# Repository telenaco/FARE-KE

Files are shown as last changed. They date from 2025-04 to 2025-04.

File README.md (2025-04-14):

# FARE-KE: Framework for Affordable, Reliable Kinesthetic Evaluation



## Overview

<p align="center">
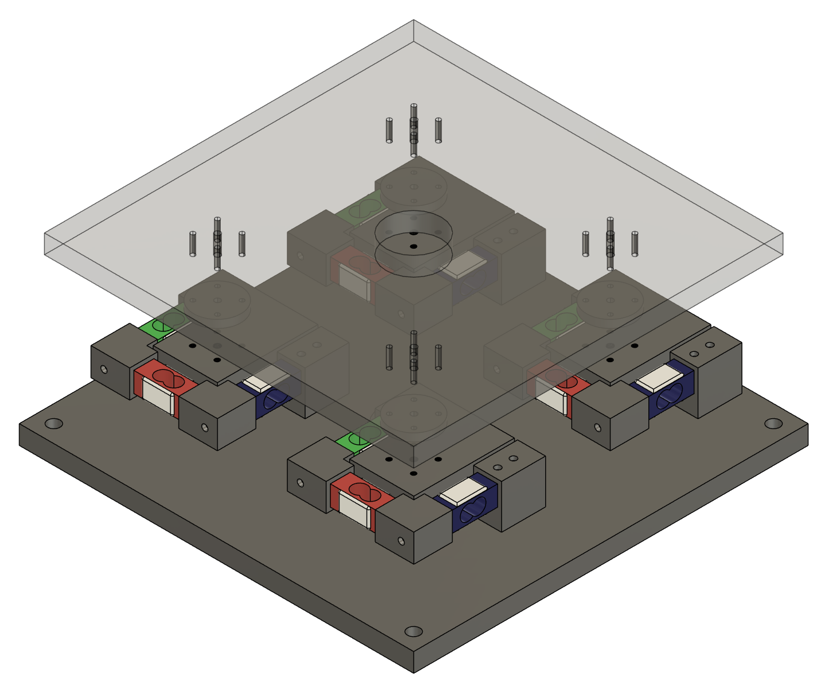
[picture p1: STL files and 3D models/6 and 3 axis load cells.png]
Figure 1: Load cell assembly
  
</p>

<p align="center"><span style="font-size: smaller;"><em>Figure 1: Exploded isometric view of the 6- and 3-axis load cell array assembly, showing the modular sensor housing units.</em></span></p>

FARE-KE is a comprehensive, standardized framework developed to address the growing need for accessible characterization methods for kinesthetic haptic devices. Born out of the challenges faced during the COVID-19 pandemic when laboratory access was limited, this framework provides researchers with the tools and methodologies to conduct precise haptic device evaluation using affordable components and open-source technologies.

The framework emerged from research on haptic device design and was refined through applications in three distinct case studies (VR Recoil, ProxyTouch, and HapticWhirl). FARE-KE aims to democratize haptic research by making characterization methods and tools accessible to researchers of all experience levels.

## Repository Structure

```
FARE-KE
├── Board_Evaluation
│   ├── ADC_Performance            # ADC testing and benchmarking studies
│   │   ├── adc_excitation_voltage_analysis  # Comparison of voltage stability
│   │   ├── adc_noise_variation_analysis     # Noise analysis at different OSR settings
│   │   └── adc_sampling_rate_analysis       # Evaluation of sampling performance
│   ├── Calibration_Methods        # Calibration methodologies for different load cells
│   │   ├── six_axis_calibration            # Matrix-based calibration approaches
│   │   └── three_axis_calibration          # Calibration for 3-axis sensors
│   └── Load_Cell_Comparison       # Comparative studies of load cell performance
│       ├── beam_load_cell_calibration      # Linear vs polynomial calibration
│       ├── beam_load_cell_comparison       # Temperature and drift analysis
│       └── hx711_vs_mcp3564_comparison     # Comparison of ADC performance
├── Haptic_Device_Testing
│   ├── Ramp_Response              # Implementation of ramp response analysis
│   │   ├── rampResponseAnalysis.py        # Analysis script for ramp data
│   │   └── rampResponseTelemetry.cpp      # Arduino code for ramp testing
│   └── Step_Response              # Implementation of step response analysis
│       ├── StepResponseAnalysis.py        # Analysis script for step data
│       └── stepResponseTelemetry.cpp      # Arduino code for step testing
├── MCP356x_Arduino_Library        # Core software components of FARE-KE
│   ├── lib/mcp356x                # Library for MCP356x ADCs
│   │   ├── examples               # Example implementations
│   │   │   ├── Basic              # Fundamental operations (reading, sampling)
│   │   │   ├── Calibration        # Calibration examples for different scenarios
│   │   │   ├── Comparison         # Comparison with other ADC technologies
│   │   │   ├── Filtering          # Signal filtering implementations
│   │   │   ├── LoadCells          # Multi-axis load cell configurations
│   │   │   └── Telemetry          # Data visualization and transmission
│   │   └── src                    # Core library source files
│   │       ├── MCP356x.cpp/h              # Base ADC interface
│   │       ├── MCP356x3axis.cpp/h         # 3-axis load cell support
│   │       ├── MCP356x6axis.cpp/h         # 6-axis force/torque plate
│   │       └── MCP356xScale.cpp/h         # Multi-load cell management
│   └── src                        # Main application code
├── MCP356x_DAQ_PCB_Board          # Hardware design for data acquisition
│   └── ffpcbBoard                 # Custom PCB for 12-channel data acquisition
│       ├── manufacturingPCB               # Gerber files for fabrication
│       └── PCB design files               # Schematics and BOM information
└── STL files and 3D models        # Physical components for framework implementation
    ├── 3-axis load cell STLs             # 3D printable parts for custom 3-axis sensors
    ├── 6-axis force plate STLs           # Components for force/torque plate assembly
    └── testbed designs                   # Mounting systems for various device types
```

## The FARE-KE Framework Architecture

FARE-KE consists of four integrated components to provide comprehensive haptic device characterization:

### 1. Hardware Framework

<p align="center">
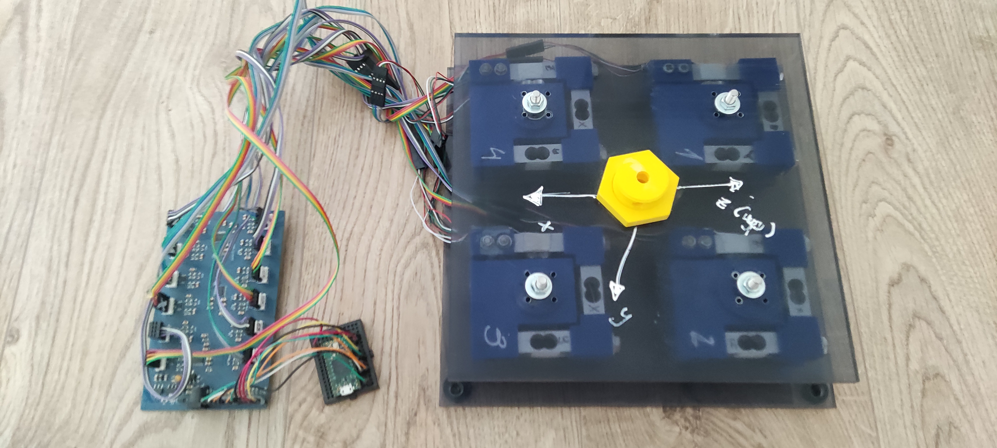
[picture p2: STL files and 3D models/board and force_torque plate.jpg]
Force/Torque Plate Assembly
  
</p>

<p align="center"><span style="font-size: smaller;"><em>Figure 2: Complete 6-axis force/torque plate with ADC board and wiring, showing the integrated system.</em></span></p>

**Key Components:**
- **Load Cells**: Single-axis beam load cells, custom 3-axis, and 6-axis configurations
- **Data Acquisition System**: Custom PCB design integrating 3 x MCP3564 ADCs for 12-channel capture
- **Testbeds**: Modular aluminum designs for mounting kinesthetic devices and sensors

**Testbed Designs:**
The framework recommends using extruded aluminum (40×40mm) for testbed construction due to:
- Standardization and wide availability
- Excellent structural rigidity (minimal vibrations)
- Abundant accessories for mounting and adaptation
- Easy reconfiguration for different device sizes

The testbeds must be designed to emulate the device's operational context and accommodate the same quantity and configuration of actuators as the final prototype to ensure representative data capture.

The framework supports five types of kinesthetic feedback modalities:

1. **Direct Single-Axis Force**: For devices applying linear force directly to the user
2. **Single-Axis Impact**: For devices generating sudden bursts of energy
3. **In-line Forces**: For cable-driven exoskeletons and similar devices
4. **Rotational Joint Torque**: For devices generating torque around a pivot point
5. **Multi-axis Force/Torque**: For complex haptic controllers with multiple degrees of freedom

### 2. Data Acquisition Framework

**Components:**
- **MCP3564 ADCs**: 24-bit sigma-delta converters supporting up to 153.6 kSPS sampling
- **Op-amp Based Amplification**: Customizable gain to optimize ADC range utilization
- **Teensy 4.0 Integration**: High-speed processing of multiple ADC channels

<p align="center">
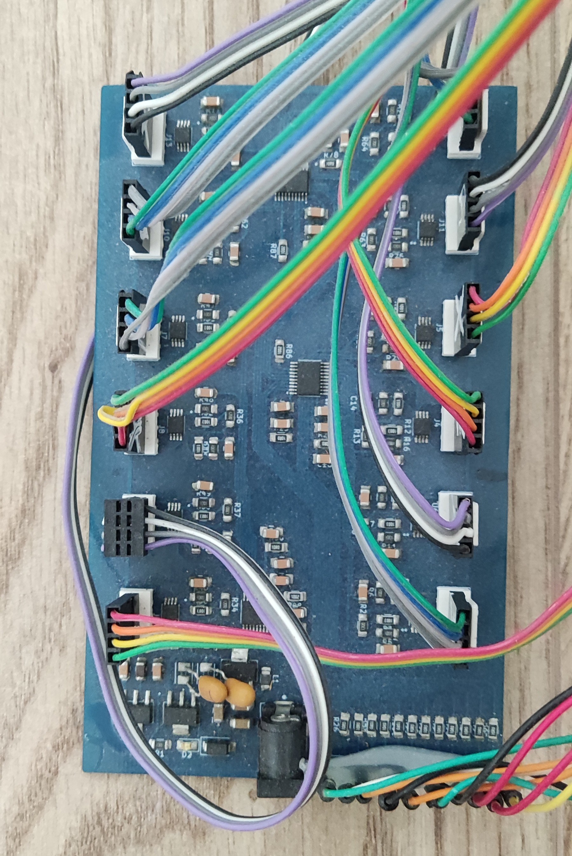
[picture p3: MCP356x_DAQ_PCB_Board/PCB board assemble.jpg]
DAQ PCB Board Assembly
  
</p>

<p align="center"><span style="font-size: smaller;"><em>Figure 4: Detailed assembly of the custom 12-channel Data Acquisition PCB, showing component layout and interconnections.</em></span></p>

<p align="center">
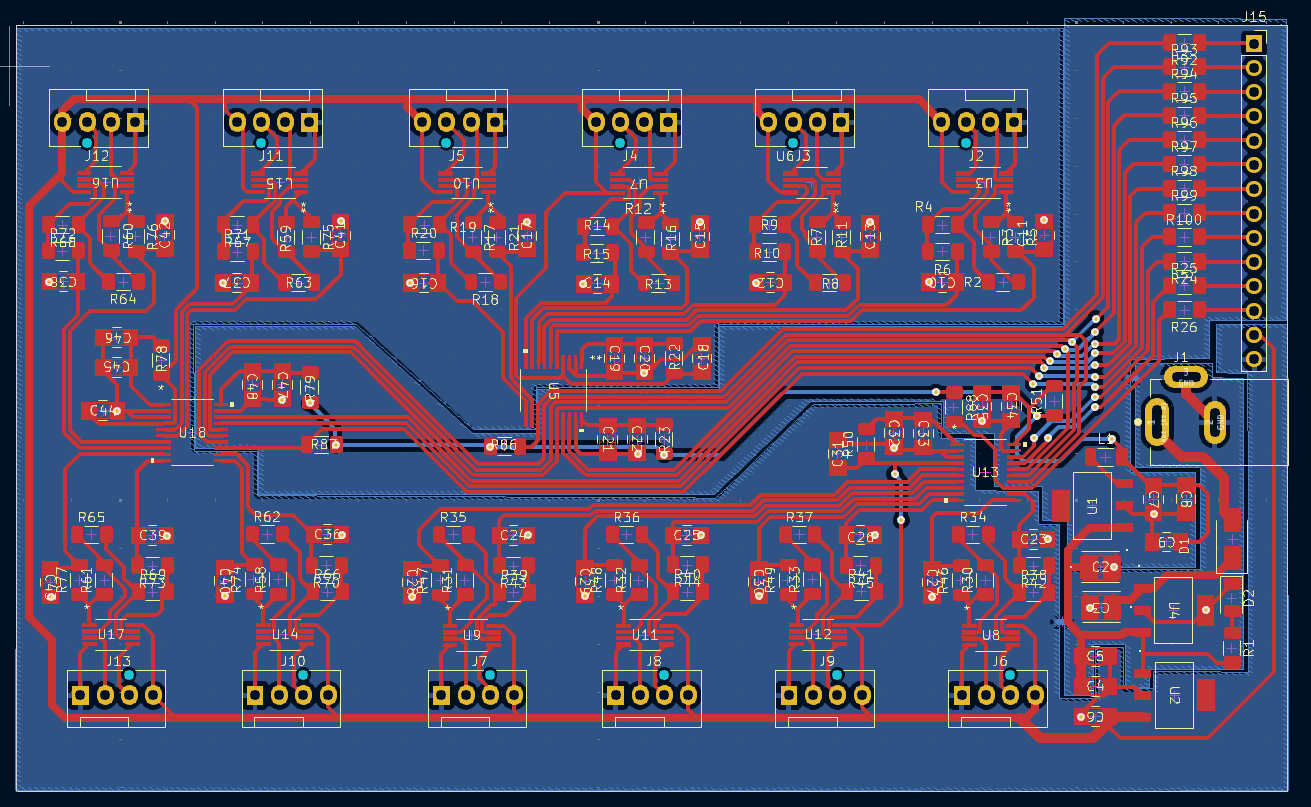
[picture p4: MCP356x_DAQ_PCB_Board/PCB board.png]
PCB Board Design
  
</p>

<p align="center"><span style="font-size: smaller;"><em>Figure 5: PCB board design schematic, illustrating the intricate routing and component placement for the 12-channel ADC system.</em></span></p>

**Key Features:**
- **Sampling Rate**: Up to 10 kSPS on a single channel with internal clock
- **Resolution**: Effective resolution of 16+ bits due to signal conditioning and oversampling
- **Channels**: Support for 12 simultaneous channels when using three ADCs

**Excitation Voltage Comparison:**
| Parameter | HX711 ADC (V) | MCP3564 ADC (V) |
|---|---|---|
| Mean voltage | 4.2913 | 3.2840 |
| Standard deviation | 0.0140 | 0.0133 |
| Range (Max - Min)  | 0.3119 | 0.2533 |

Both ADC circuits exhibit similar interference levels in the frequency domain. The MCP3564 showed a slightly smaller standard deviation.

### 3. Calibration Framework

**Calibration Approaches:**
- **Single-Axis Calibration**: Polynomial regression providing up to 0.9999 R² fit
- **3-Axis Calibration**: Multi-point calibration with matrix-based crosstalk compensation
- **6-Axis Calibration**: Least-squares optimization for complex force/torque interactions

<p align="center">
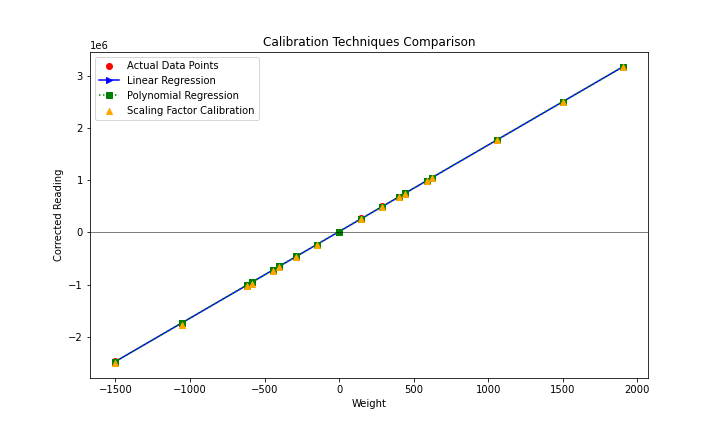
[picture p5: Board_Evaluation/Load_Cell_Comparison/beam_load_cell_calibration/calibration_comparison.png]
Calibration Techniques Comparison
 
</p>

<p align="center"><span style="font-size: smaller;"><em>Figure 6: Comparative analysis of different calibration techniques for beam load cells, demonstrating the linearity and accuracy of polynomial regression, linear regression, and scaling factor methods.</em></span></p>

**Calibration Mathematics:**

For single-axis load cells, three calibration approaches are evaluated:
1. **Scaling Factor**: `y = Kx` where K is a constant factor
2. **Linear Regression**: `y = mx + b` where m is slope and b is intercept
3. **Polynomial Regression**: `y = ax² + bx + c` for nonlinear behavior

For 3-axis load cells, the calibration matrix (K) accounts for both sensitivity and crosstalk:
```
[Fx]   [K11 K12 K13] [Rx]
[Fy] = [K21 K22 K23] [Ry]
[Fz]   [K31 K32 K33] [Rz]
```
Where Fx, Fy, Fz are forces, and Rx, Ry, Rz are sensor readings.

For the 6-axis force/torque plate, the 12 individual load cell readings are combined to calculate forces and torques:
```
Fx = LCAxf + LCBxf + LCCxf + LCDxf
Fy = LCAyf + LCByf + LCCyf + LCDyf
Fz = LCAzf + LCBzf + LCCzf + LCDzf
Mx = (plateLength/2) * (LCAzf + LCBzf - LCCzf - LCDzf)
My = (plateWidth/2) * (-LCAzf + LCBzf + LCCzf - LCDzf)
Mz = (plateWidth/2) * (LCAyf - LCByf + LCCyf - LCDyf) + 
     (plateLength/2) * (LCAxf + LCBxf - LCCxf - LCDxf)
```
Where LC[A-D][x-z]f represents force readings from each load cell in each direction.

### 4. Analysis Framework

**Performance Metrics:**
- **Physical Properties**: 7 metrics describing basic device characteristics
- **Ramp Analysis**: 7 metrics capturing force capabilities and static behavior
- **Step Response Analysis**: 5 metrics describing dynamic performance

## Hardware Components

### Data Acquisition System

The core of the FARE-KE framework is a custom 12-channel DAQ board built around the MCP3564 24-bit ADC:

- **Channels:** 12 differential input channels (3 MCP3564 ADCs × 4 channels each)
- **Resolution:** 24-bit per channel
- **Sampling Rate:** Up to 11.59 kSPS per channel with OSR=32
- **Multiple Configurations:** Adjustable oversampling ratio (OSR) to balance between noise rejection and sampling speed
- **Amplification:** Integrated amplification stage with MCP6V97 op-amps
- **Power Supply:** 5-12V input with separate analog and digital power domains
- **Power Consumption:** ~76.4mA with all 12 channels active

The PCB design files are available in the `MCP356x_DAQ_PCB_Board/ffpcbBoard/manufacturingPCB/` directory.

### Load Cell Configurations

#### 1. Single-Axis Beam Load Cells

The framework has validated the performance of three models:

- **TAL220:** 10kg capacity, demonstrated excellent linearity (R² > 0.999)
- **Degraw:** 5kg capacity, good performance with slightly higher noise
- **CZL635:** 5kg capacity, good performance with lower noise

| Load Cell | Capacity (kg) | Slope (counts/gf) | R² Value | Sensitivity (mgf) | Peak-to-peak noise (gf) |
|---|---|---|---|---|---|
| TAL220 | 10 | 1787.65 | 0.99998  | 0.56 | 17.105 |
| Degraw | 5 | 2517.44 | 0.99995  | 0.40 | 10.152 |
| CZL635 | 5 | 3033.73 | 0.99997  | 0.33 | 9.784 |

**Temperature Drift Analysis:**
All three load cells showed sensitivity to temperature fluctuations, but with different characteristics:
- **TAL220:** Strong positive linear correlation with temperature (Pearson: 0.93, Spearman: 0.97)
- **Degraw:** Strong negative linear correlation (Pearson: -0.78, Spearman: -0.93)
- **CZL635:** Moderate positive correlation (Pearson: 0.54) but weaker monotonic relationship (Spearman: 0.12)

The maximum observed deviation was approximately 10gf over a 24-hour period (0.435% of the reading).

#### 2. Button & S-Type Load Cells

For specific applications requiring in-line force measurement:

| Load Cell Model | Max capacity | Cost  | Type | Dimensions (mm) |
|---|---|---|---|---|
| Honeywell FSS015WNSB | 1.5kg | ~70€  | Compression Load Cell | 9.14x3.18x5.59 |
| Phidget Button Load Cell| 50kg | ~45€  | Compression Load Cell | 9mm height 25mm ⌀ |
| Phidget Button Load Cell| 200kg | ~45€  | Compression Load Cell | 9mm height 25mm ⌀ |
| DYLY-106 (S-type) | 10kg | ~50€  | S-Type Load Cell | 25x30x12mm |

These offer advantages for inline force measurements but typically cost more due to complex manufacturing.

#### 3. 3-Axis Load Cell

Custom-designed assemblies using three single-axis beam load cells arranged orthogonally:

- 3D-printed components ensure proper alignment
- Calibration matrices compensate for crosstalk between axes
- Validated using polynomial regression calibration methods

<p align="center">
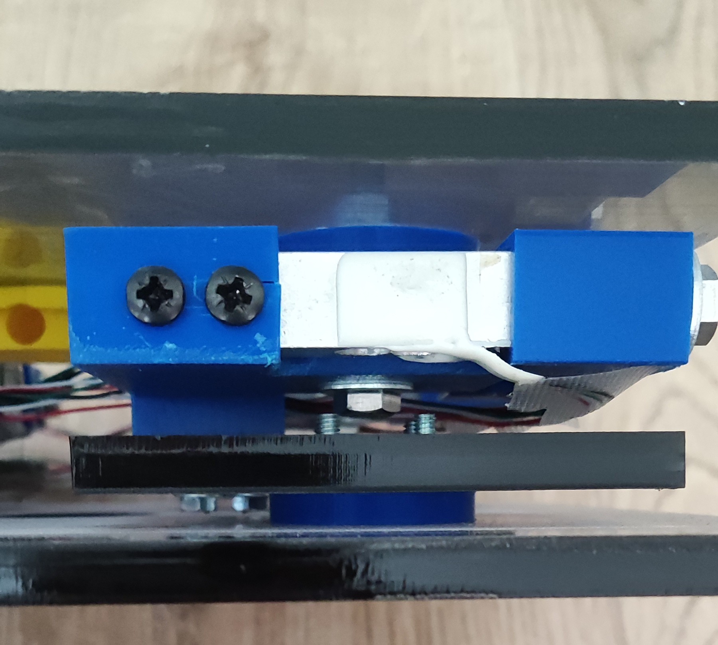
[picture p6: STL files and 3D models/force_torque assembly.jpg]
3-Axis Load Cell Mounting Detail
  
</p>

<p align="center"><span style="font-size: smaller;"><em>Figure 3: Side view of a 3-axis load cell mounted on the force/torque plate, showing mounting method.</em></span></p>

| Calibration Method | MAE (g) | RMSE (g) | Max Error (g) |
|---|---|---|---|
| Single-Point | 8.91 | 15.24 | 70.43 |
| Least Squares | 8.70 | 14.72 | 67.29 |
| Polynomial Regression | 7.54 | 11.28 | 44.93 |

**Assembly Process:**
1. Apply aluminum epoxy to the load cell holders
2. Mount load cells using 3D-printed parts (base, elbows, center piece)
3. Mark and drill 2.5mm holes through the load cells
4. Tap the holes to create 3mm threads
5. Secure joints using M3 screws

#### 4. 6-Axis Force/Torque Plate

Comprehensive solution for measuring forces and torques in all directions:

- Four 3-axis load cells arranged between two acrylic plates (12mm thick)
- 12 total channels measuring force components
- Mathematical algorithms combine readings to calculate 3 forces and 3 torques
- Multipoint calibration procedures compensate for crosstalk and nonlinear behavior

| Metric | Raw Readings | Calibrated |
|---|---|---|
| MAPE (%)  | 2.814737 | 1.849263 |
| R-squared | 0.983804 | 0.999691 |

**Crosstalk Reduction:**
The calibration matrix substantially reduced crosstalk, particularly along the torque axes:

| Axis | Pre-calibration Std Dev | Post-calibration Std Dev | Improvement Factor |
|---|---|---|---|
| Fx | 0.1139 | 0.0224 | ~5x |
| Fy | 0.0821 | 0.0377 | ~2x |
| Fz | 0.3907 | 0.0343 | ~11x |
| Mx | 0.0846 | 0.0154 | ~5.5x |
| My | 0.0979 | 0.0085 | ~11.5x |
| Mz | 0.0528 | 0.0043 | ~12x |

### Microcontroller

The framework is designed to work with Teensy 4.0 microcontrollers:

- 600 MHz ARM Cortex-M7 processor
- Support for high-speed SPI communication (up to 20 MHz)
- USB connectivity for data logging and visualization
- Sufficient I/O pins for multiple ADC control

## Software Components

### Core Library Structure

The `MCP356x_Arduino_Library` implements a hierarchical class structure:

- **MCP356x:** Base class for interfacing with the MCP3564 ADC
- **MCP356xScale:** Mid-level class for managing single-axis load cells
- **MCP356x3axis:** Class for 3-axis load cell measurement and calibration
- **MCP356x6axis:** High-level class for the complete force/torque plate

### Calibration Utilities

Located in `Board_Evaluation/Calibration_Methods/`, these tools provide:

- Single-axis load cell calibration using polynomial regression
- 3-axis load cell calibration with crosstalk compensation
- 6-axis force/torque plate multipoint calibration
- Validation scripts to verify calibration accuracy

### Analysis Scripts

The `Haptic_Device_Testing/` directory contains scripts for standardized performance evaluation:

- **Ramp Response Analysis:** `rampResponseTelemetry.cpp` and `rampResponseAnalysis.py`
- **Step Response Analysis:** `stepResponseTelemetry.cpp` and `StepResponseAnalysis.py`

### Data Logging Tools

Two primary tools are supported for data acquisition and visualization:

**TyCommander:**
- Standalone utility designed for communication with Teensy microcontrollers
- Real-time data monitoring and message printing via serial communication
- Ability to save received data as CSV files
- Reliable performance at high baud rates (unlike Arduino Serial Monitor or PuTTY)

**Telemetry Viewer:**
- Advanced data visualization and logging capabilities
- Customizable telemetry panels to monitor data streams from diverse sources
- Support for multiple serial ports and Wi-Fi
- Real-time data visualization with customizable layouts
- Data export to CSV format for further analysis

## Getting Started

### Hardware Setup

1. **Assemble the Data Acquisition Board:**
   - Manufacture the PCB using files in `MCP356x_DAQ_PCB_Board/ffpcbBoard/manufacturingPCB/`
   - Assemble components according to the BOM

2. **Prepare Load Cells:**
   - For single-axis measurements, connect beam load cells directly
   - For 3-axis measurements, follow the assembly guide in Appendix 18
   - For 6-axis measurements, assemble the force/torque plate following Appendix 23

3. **Connect Microcontroller:**
   - Connect Teensy 4.0 to the DAQ board using SPI pins
   - Connect to computer via USB for programming and data logging

### Software Setup

1. **Development Environment:**
   - Install VSCode and PlatformIO extension
   - Open the `MCP356x_Arduino_Library` folder in PlatformIO
   - Required dependencies included on the folder (BasicLinearAlgebra, ....)

2. **Upload Firmware:**
   - For basic testing, use examples from `MCP356x_Arduino_Library/lib/mcp356x/examples/`
   - For performance characterization, use scripts from `Haptic_Device_Testing/`

3. **Calibration:**
   - Follow the calibration procedures appropriate for your load cell configuration
   - Use Python scripts in `Board_Evaluation/Calibration_Methods/` to calculate calibration matrices

4. **Data Collection:**
   - Use TyCommander or Telemetry Viewer for real-time data visualization
   - Export data to CSV for further analysis

## Characterization Process

FARE-KE standardizes haptic device characterization through three methodologies:

### 1. Physical Properties Assessment

Document basic device characteristics:

| Variable | Metrics | Relevance |
|---|---|---|
| Workspace | XYZ mm | Determines the physical range in which the device can operate |
| Degrees of Freedom | 2x rot., 1x transl. | Identifies the independent directions in which the device can move or rotate |
| Electrical Properties | Voltage, Power | Defines the electrical requirements for the device to function properly |
| Device Dimensions | XYZ mm | Specifies the physical size of the device, important for compatibility with use cases |
| Weight | grams | Indicates the heaviness of the device which can impact user comfort and device portability |
| Operational Noise | decibels | Provides an idea of the acoustic disturbance caused by the device during operation |
| Vibrations | m/s² | Measures the mechanical vibrations generated by the device, which can affect user experience |

### 2. Ramp Response Analysis

Characterizes static properties and load-dependent behavior:

| Variable | Metrics | Relevance |
|---|---|---|
| Max Force/Torque | Newtons | Determines the maximum force or torque that the device can exert |
| Min Force/Torque | Newtons | Specifies the smallest detectable force or torque that the device can exert |
| Hysteresis | Newtons | Describes the lag in response exhibited by the device when subjected to changing inputs |
| Sensitivity | Newtons/Volt | Measures the change in force output per unit change in input signal |
| Output Force Resolution | Newtons | Identifies the smallest detectable change in force output by the device |
| Dynamic Range | dB | Captures the range of force output the device can provide, from the minimum to maximum force |
| Stiffness | Newtons/mm | Quantifies the resistance of the device to deformation in response to an applied force |

Hysteresis is calculated as the maximum difference between increasing and decreasing output curves:
```
Hysteresis = max(F_decreasing - F_increasing)
```

Dynamic range is calculated in decibels:
```
Dynamic Range (dB) = 20 * log10(Max_Force / Min_Force)
```

### 3. Step Response Analysis

Evaluates dynamic characteristics:

| Variable | Metrics | Relevance |
|---|---|---|
| Peak Force (overshoot) | Newtons | Records the maximum force output by the device in response to a sudden change in input |
| Continuous Force | Newtons | Measures the force that the device can maintain continuously over a prolonged period |
| Rise time | Seconds | Notes the time it takes for the device to reach the desired output from an initial state |
| Settling Time | Seconds | Measures the time the device takes to stabilize after a change in input |
| Output Error | % | Provides an estimation of the error between the desired and actual output of the device  |

Rise time is typically measured from 10% to 90% of the continuous force output. Settling time is measured as the time until output stabilizes within 5% of the final value.

## Performance Considerations

### ADC Performance

The MCP3564 ADC performance varies based on Oversampling Ratio (OSR) settings:

| OSR Setting | Sampling kSPS | Standard Deviation | SNR (dB) | SD (gf) | 95% CI (gf) |
|---|---|---|---|---|---|
| 32 | 11.59 | 4921.15 | 24.34 | 2.99 | ±5.98 |
| 64 | 5.79 | 4247.45 | 23.70 | 2.59 | ±5.17 |
| 128 | 2.90 | 3714.84 | 23.20 | 2.26 | ±4.53 |
| 256 | 1.45 | 3211.98 | 23.13 | 1.96 | ±3.91 |
| 512 | 0.72 | 2864.04 | 23.82 | 1.74 | ±3.49 |
| 1024 | 0.54 | 2707.46 | 24.29 | 1.65 | ±3.30 |
| 2048 | 0.36 | 2489.31 | 25.04 | 1.52 | ±3.03 |
| 4096 | 0.22 | 2318.21 | 25.68 | 1.41 | ±2.82 |

Increasing OSR improves signal quality (higher SNR, lower standard deviation) at the cost of reduced sampling rate. For applications requiring both high sampling rates and good signal quality, the OSR setting should be balanced according to specific requirements.

Multi-channel sampling reduces the effective sampling rate proportionally to the number of channels:

| OSR Setting | Single Channel (kSPS) | Four Channels (kSPS) |
|---|---|---|
| 32 | 11.59 | 2.8975 |
| 64 | 5.79 | 1.4475 |
| 128 | 2.90 | 0.725 |
| 256 | 1.45 | 0.3625 |

With external 20MHz clock (potential future development), sampling rates could reach:
- 38.4 kSPS for single channel (OSR=32)
- 9.6 kSPS for four channels (OSR=128)

### Comparison with HX711

<p align="center">
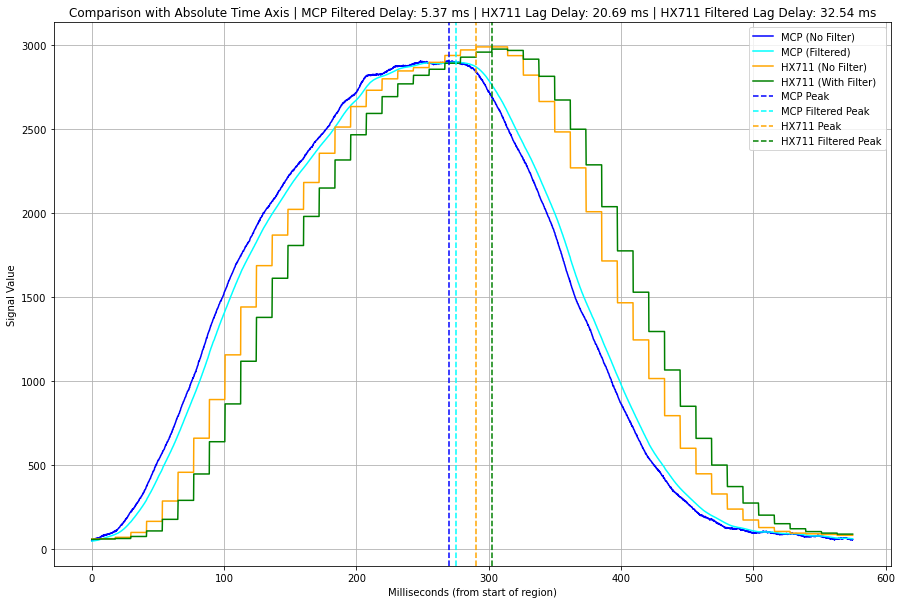
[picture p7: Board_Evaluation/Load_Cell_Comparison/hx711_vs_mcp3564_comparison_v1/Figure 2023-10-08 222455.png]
MCP3564 vs HX711 Comparison
 
</p>

<p align="center"><span style="font-size: smaller;"><em>Figure X: Comparative signal analysis showing the delay and response characteristics of MCP3564 and HX711 ADCs, highlighting the superior temporal resolution of the MCP3564.</em></span></p>

MCP3564 offers significant advantages over the commonly used HX711:

- **Sampling Rate**: MCP3564 samples at 11.59 kSPS vs. HX711's 80 SPS
- **Latency**: MCP3564 filtered data has 8.9ms delay vs. HX711's 42.5ms
- **Impact Capture**: MCP3564 captures transient peaks that HX711 misses

| Signal Type | Average Lag Delay (ms) |
|---|---|
| MCP_no_filter | - |
| mcp_filtered_data | 8.9 |
| HX_no_filter | 20.64 |
| HX_with_filter | 42.50 |

In impact testing, the MCP3564 recorded impulses of ~0.39 Ns compared to the HX711's ~0.345-0.335 Ns, showing better accuracy in capturing transient events.

## References

For detailed information about the framework design, implementation, and validation, refer to:

- **Thesis Chapter 3:** FARE-KE Framework Overview
- **Thesis Chapter 4:** Data Acquisition Board Design
- **Thesis Chapter 5:** Sensor/Hardware Validation
- **Appendix 14:** Instrument Amplifier Comparison
- **Appendix 18:** 3-Axis Load Cell Assembly Guide
- **Appendix 20:** 3-Axis Single Point Calibration
- **Appendix 21:** 3-Axis Multipoint Calibration
- **Appendix 23:** 6-Axis Load Cell Multipoint Calibration
- **Appendix 24:** Analysis Implementations

## License

This project is released under the MIT License. See the LICENSE file for details.

## Citation

If you use FARE-KE in your research, please cite:

```
@thesis{bernamoya2025fare,
  title={FARE-KE: Framework for Affordable, Reliable Kinesthetic Evaluation},
  author={Berna Moya, Jose Luis},
  year={2025},
  school={University of Sussex}
}
```

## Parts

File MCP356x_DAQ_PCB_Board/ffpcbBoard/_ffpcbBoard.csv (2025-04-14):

Reference(s) | Qty | Value | LibPart | Footprint | Datasheet | DNP | MANUFACTURER | P_Footprint | P_Voltage | P_footprint | P_tolerance | STANDARD | Sim.Device | Sim.Pins
C2 | 1 | 10 µF | :TAJB106K010RNJ_1 | footprints:TAJB_AVX-M | TAJB106K010RNJ
C3 | 1 | 10 µF | 6:TAJB106K010RNJ | footprints:TAJB_AVX-M | TAJB106K010RNJ
C4 | 1 | 10 µF | :C1206C106K8RACTU_5 | footprints:CAPC340180_180N_KEM-M | C1206C106K8RACTU
C5 | 1 | 0.1 µF | one:C1206C106K8RACTU | footprints:CAPC340180_180N_KEM-M | C1206C106K8RACTU
C6 | 1 | 1 µF | :C1206C106K8RACTU_4 | footprints:CAPC340180_180N_KEM-M | C1206C106K8RACTU
C7 | 1 | 100 µF | :C1206C106K8RACTU_2 | footprints:CAPC340180_180N_KEM-M | C1206C106K8RACTU
C8 | 1 | 100 µF | :C1206C106K8RACTU_1 | footprints:CAPC340180_180N_KEM-M | C1206C106K8RACTU
C9 | 1 | 100 µF | :C1206C106K8RACTU_3 | footprints:CAPC340180_180N_KEM-M | C1206C106K8RACTU
C10, C11, C12, C13, C14, C15, C16, C17, C23, C24, C25, C26, C27, C28, C29, C30, C36, C37, C38, C39, C40, C41, C42, C43 | 24 | 0.1 µF | :C1206C106K8RACTU_1 | footprints:CAPC340180_180N_KEM-M | C1206C106K8RACTU |  |  | 1206 | 10V
C18, C19, C20, C21, C22, C31, C32, C33, C34, C35, C44, C45, C46, C47, C48 | 15 | 0.1 µF | :C1206C106K8RACTU_4 | footprints:CAPC340180_180N_KEM-M | C1206C106K8RACTU
D1 | 1 | NRVA4005T3G | Diode:NRVA4005T3G | Diode_SMD:D_SMA | http://www.onsemi.com/pub_link/Collateral/MRA4003T3-D.PDF |  |  |  |  |  |  |  | D | 1=K 2=A
D2 | 1 | LED | Device:LED | LED_SMD:LED_1206_3216Metric | ~
J1 | 1 | PJ-002A | PJ-002A:PJ-002A | footprints_0:CUI_PJ-002A |  |  | CUI INC |  |  |  |  | Manufacturer recommendations
J2, J3, J4, J5, J6, J7, J8, J9, J10, J11, J12, J13 | 12 | Conn_01x04 | Connector_Generic:Conn_01x04 | Connector:FanPinHeader_1x04_P2.54mm_Vertical | ~
J15 | 1 | Conn_01x14 | Connector_Generic:Conn_01x14 | Connector_PinSocket_2.54mm:PinSocket_1x14_P2.54mm_Vertical | ~
L1 | 1 | 4.7 µH | Device:L | Inductor_SMD:L_1206_3216Metric_Pad1.22x1.90mm_HandSolder | ~
R1, R5, R6, R10, R11, R15, R16, R20, R21, R42, R43, R44, R45, R46, R47, R48, R49, R70, R71, R72, R73, R74, R75, R76, R77 | 25 | 1k? | Device:R | Resistor_SMD:R_1206_3216Metric_Pad1.30x1.75mm_HandSolder | ~ |  |  |  |  | 1206 | 1%
R2, R8, R13, R18, R34, R35, R36, R37, R62, R63, R64, R65 | 12 | 2k? | Device:R | Resistor_SMD:R_1206_3216Metric_Pad1.30x1.75mm_HandSolder | ~ |  |  |  |  | 1206 | 0.10%
R3, R4, R7, R9, R12, R14, R17, R19, R30, R31, R32, R33, R38, R39, R40, R41, R58, R59, R60, R61, R66, R67, R68, R69 | 24 | 100k? | Device:R | Resistor_SMD:R_1206_3216Metric_Pad1.30x1.75mm_HandSolder | ~ |  |  |  |  | 1206 | 1%
R22, R23, R24, R25, R26, R50, R51, R78, R79, R92, R93, R94, R95, R96, R97, R98, R99, R100 | 18 | 10R | Device:R | Resistor_SMD:R_1206_3216Metric_Pad1.30x1.75mm_HandSolder | ~ |  |  |  |  | 1206 | 5%
R86, R87, R88 | 3 | 10K? | Device:R | Resistor_SMD:R_1206_3216Metric_Pad1.30x1.75mm_HandSolder | ~ |  |  |  |  | 1206 | 5%
U1 | 1 | MCP1754ST-5002E/DB | two:MCP1754ST-5002E_DB | footprints:SOT-223_3MC_MCH-M | MCP1754ST-5002E/DB
U2 | 1 | MCP1825S-3002E/DB | 3:MCP1825S-3002E_DB | footprints:SOT-223_3MC_MCH-M | MCP1825S-3002E/DB
U3, U6, U7, U8, U9, U10, U11, U12, U14, U15, U16, U17 | 12 | MCP6V97-E/MS | 4:MCP6V97-E_MS | footprints:MSOP8_MS_MCH-M | MCP6V97-E/MS
U4 | 1 | MIC39100-5.0WS | 5:MIC39100-5.0WS | footprints:SOT-223_S_MCL-M | MIC39100-5.0WS
U5, U13, U18 | 3 | MCP3564-E/ST | MPC3564:MCP3564-E_ST | footprints_1:TSSOP20_ST_MCH-M | MCP3564-E/ST

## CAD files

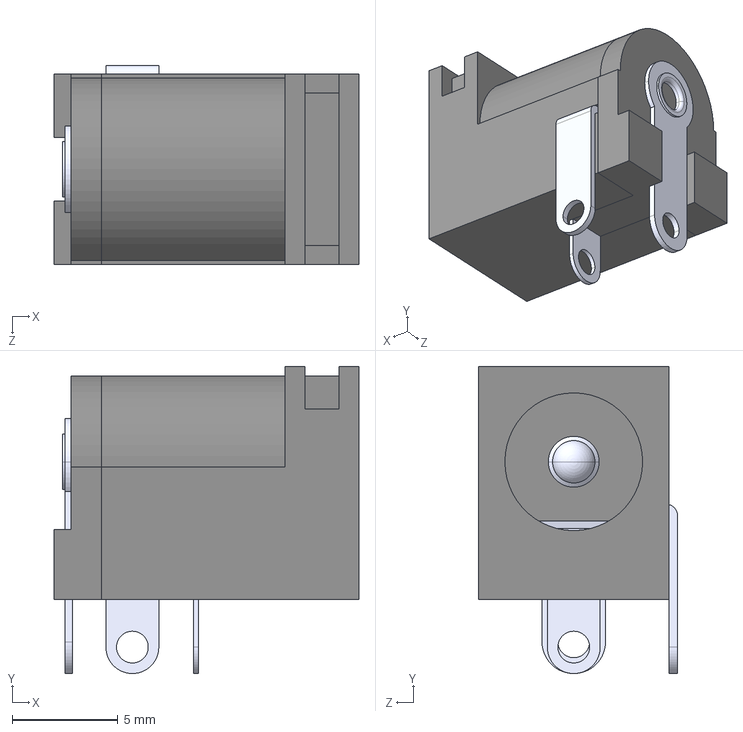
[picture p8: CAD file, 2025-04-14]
MCP356x_DAQ_PCB_Board/Components Library/PJ-002A/PJ-002A.step
14.4 x 14.5 x 9.40 mm

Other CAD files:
STL files and 3D models/6 axis force torque v1.f3d

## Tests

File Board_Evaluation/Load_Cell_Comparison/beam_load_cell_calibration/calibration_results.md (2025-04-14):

# Calibration Results for Single-Axis Load Cell

This document presents the results of applying three different calibration techniques to sensor readings obtained from a single-axis load cell.

## Calibration Techniques
- **Linear Regression**
- **Polynomial Regression**
- **Scaling Factor Calibration**

Calibration Techniques Comparison

## Statistical Analysis

| Technique |  R^2 |
| --- |  --- |
| Linear Regression | 1.0000 |
| Polynomial Regression | 1.0000 |
| Scaling Factor | 0.9998 |

## Regression Equations

- **Linear Regression Equation**: $y = 1658.9607x + 15511.4743$
- **Polynomial Regression Equation**: $y = -0.0004x^2 + 1659.1182x + 15747.2728$
- **Scaling Factor**: $1669.5857$

The analysis includes Mean Squared Error (MSE) and R^2 scores for each calibration method to help determine the most accurate approach for converting sensor readings into weight measurements.

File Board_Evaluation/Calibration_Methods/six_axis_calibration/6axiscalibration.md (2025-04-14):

# 6-Axis Load Cell Calibration Results

## K Matrix (Sensitivity Matrix)
This matrix represents the sensitivity of the load cell to the applied loads.

| Fx | Fy | Fz | Mx | My | Mz |
|---|---|---|---|---|---|
| 0.3927 | 0.0061 | -0.0105 | 0.0021 | 0.0240 | -0.0052 |
| -0.0124 | 0.4095 | 0.0068 | 0.0057 | -0.0088 | 0.0065 |
| 0.0084 | -0.0166 | 0.4210 | 0.0092 | -0.0027 | 0.0072 |
| 0.0026 | 0.0029 | 0.0047 | 0.1796 | 0.0038 | -0.0049 |
| 0.0008 | 0.0024 | -0.0081 | 0.0050 | 0.2004 | 0.0001 |
| -0.0068 | 0.0007 | 0.0050 | 0.0031 | -0.0054 | 0.1810 |

## Inverse of K Matrix (K^-1)
The inverse matrix is used for compensating the cross-talk between different channels.

| Fx | Fy | Fz | Mx | My | Mz |
|---|---|---|---|---|---|
| 2.5465 | -0.0338 | 0.0575 | -0.0244 | -0.3035 | 0.0718 |
| 0.0763 | 2.4399 | -0.0336 | -0.0783 | 0.0965 | -0.0857 |
| -0.0489 | 0.0976 | 2.3759 | -0.1239 | 0.0420 | -0.1025 |
| -0.0333 | -0.0409 | -0.0665 | 5.5723 | -0.1013 | 0.1528 |
| -0.0128 | -0.0242 | 0.0979 | -0.1432 | 4.9941 | -0.0089 |
| 0.0970 | -0.0140 | -0.0590 | -0.0969 | 0.1386 | 5.5279 |

## Verification (K * K^-1 = Identity Matrix)
Multiplying the K matrix by its inverse should result in an identity matrix, verifying the calculations.

| I1 | I2 | I3 | I4 | I5 | I6 |
|---|---|---|---|---|---|
| 1.0000 | -0.0000 | -0.0000 | 0.0000 | -0.0000 | 0.0000 |
| -0.0000 | 1.0000 | 0.0000 | 0.0000 | -0.0000 | -0.0000 |
| -0.0000 | -0.0000 | 1.0000 | -0.0000 | 0.0000 | -0.0000 |
| -0.0000 | 0.0000 | -0.0000 | 1.0000 | -0.0000 | -0.0000 |
| 0.0000 | 0.0000 | -0.0000 | -0.0000 | 1.0000 | -0.0000 |
| 0.0000 | -0.0000 | 0.0000 | 0.0000 | 0.0000 | 1.0000 |

## Compensated Measurements
Applying the inverse matrix to the raw measurements to obtain compensated load values.

| Axis | Raw Measurement (mV/V) | Compensated Load |
|---|---|---|
| Fx | -1.6510 | -4.49 |
| Fy | 0.6151 | 1.37 |
| Fz | 0.2501 | 0.65 |
| Mx | 1.0054 | 5.53 |
| My | 0.8402 | 4.08 |
| Mz | 0.0067 | -0.13 |

## Accuracy Metrics
Mean Absolute Error: 0.07
Max Absolute Error: 0.18

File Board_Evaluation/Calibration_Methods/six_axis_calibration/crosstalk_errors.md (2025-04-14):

Crosstalk Error From Raw Readings Table (First 10 Values):
| Fx | Fy | Fz | Mx | My | Mz |
|---:|---:|---:|---:|---:|---:|
| 0.026 | 0.049 | 0.013 | 0.001 | 0.002 | 0.002 |
| 0.006 | 0 | 0 | 0.01  | 0.002 | 0.002 |
| 0.015 | 0 | 0.018 | 0.029 | 0.001 | 0.002 |
| 0.042 | 0 | 0.031 | 0.045 | 0.002 | 0.011 |
| 0.055 | 0 | 0.048 | 0.059 | 0 | 0.002 |
| 0.107 | 0 | 0.074 | 0.093 | 0 | 0.022 |
| 0.18  | 0 | 0.129 | 0.156 | 0 | 0.037 |
| 0.301 | 0 | 0.22  | 0.258 | 0.001 | 0.062 |
| 0.453 | 0 | 0.283 | 0.362 | 0.001 | 0.089 |
| 0.594 | 0 | 0.363 | 0.483 | 0.003 | 0.116 |

Calibrated Crosstalk Error Table (First 10 Values):
| Fx | Fy | Fz | Mx | My | Mz |
|---:|---:|---:|---:|---:|---:|
| 0.026 | 0.049 | 0.013 | 0 | 0.003 | 0.002 |
| 0.023 | 0 | 0.011 | 0.003 | 0.003 | 0.001 |
| 0.025 | 0 | 0.008 | 0.004 | 0.002 | 0.006 |
| 0.015 | 0 | 0.006 | 0.001 | 0.003 | 0 |
| 0.022 | 0 | 0.001 | 0.004 | 0.001 | 0.013 |
| 0 | 0 | 0.005 | 0.006 | 0.001 | 0.001 |
| 0.004 | 0 | 0.011 | 0.006 | 0.001 | 0.001 |
| 0.01  | 0 | 0.021 | 0.005 | 0.001 | 0.001 |
| 0.017 | 0 | 0.004 | 0.007 | 0.001 | 0.004 |
| 0.002 | 0 | 0.015 | 0.003 | 0 | 0 |

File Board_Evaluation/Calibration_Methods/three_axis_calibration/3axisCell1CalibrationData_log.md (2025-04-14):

### Estimated forces (gramsForce) and Absolute Errors using Least Squares Method:
| Calculated X | Calculated Y | Calculated Z | Error X | Error Y | Error Z |
|---|---|---|---|---|---|
| 	0.0 | 	0.0 | 	0.0 | 	0.0 | 	0.0 | 	0.0 |
| 	151.3 | 	2.3 | 	2.6 | 	0.3 | 	2.3 | 	2.6 |
| 	287.0 | 	4.7 | 	5.4 | 	0.0 | 	4.7 | 	5.4 |
| 	589.3 | 	10.2 | 	9.4 | 	0.3 | 	10.2 | 	9.4 |
| 	872.1 | 	14.7 | 	13.0 | 	0.0 | 	14.7 | 	13.0 |
| 	0.0 | 	0.0 | 	0.0 | 	0.0 | 	0.0 | 	0.0 |
| 	1.8 | 	152.7 | 	-4.4 | 	1.8 | 	1.7 | 	4.4 |
| 	4.2 | 	289.8 | 	-8.7 | 	4.2 | 	2.8 | 	8.7 |
| 	9.5 | 	589.2 | 	-15.7 | 	9.5 | 	0.2 | 	15.7 |
| 	14.1 | 	870.7 | 	-24.6 | 	14.1 | 	1.4 | 	24.6 |
| 	0.0 | 	0.0 | 	0.0 | 	0.0 | 	0.0 | 	0.0 |
| 	-2.4 | 	-3.7 | 	-151.1 | 	2.4 | 	3.7 | 	0.1 |
| 	-4.6 | 	-6.7 | 	-286.6 | 	4.6 | 	6.7 | 	0.4 |
| 	-9.7 | 	-15.7 | 	-588.8 | 	9.7 | 	15.7 | 	0.2 |
| 	-12.1 | 	-24.5 | 	-871.8 | 	12.1 | 	24.5 | 	0.3 |

### Estimated forces (gramsForce) and Absolute Errors using Polynomial Regression Method:
| Calculated X | Calculated Y | Calculated Z | Error  X | Error Y | Error Z |
|---|---|---|---|---|---|
| 	-5.9 | 	3.1 | 	-1.6 | 	5.9 | 	3.1 | 	1.6 |
| 	147.9 | 	1.3 | 	2.4 | 	3.1 | 	1.3 | 	2.4 |
| 	285.3 | 	0.0 | 	6.4 | 	1.7 | 	0.0 | 	6.4 |
| 	589.6 | 	-2.7 | 	13.2 | 	0.6 | 	2.7 | 	13.2 |
| 	872.1 | 	-5.8 | 	19.3 | 	0.0 | 	5.8 | 	19.3 |
| 	-5.9 | 	3.1 | 	-1.6 | 	5.9 | 	3.1 | 	1.6 |
| 	-2.3 | 	152.4 | 	-4.5 | 	2.3 | 	1.4 | 	4.5 |
| 	1.7 | 	287.7 | 	-7.5 | 	1.7 | 	0.7 | 	7.5 |
| 	10.5 | 	586.8 | 	-11.6 | 	10.5 | 	2.2 | 	11.6 |
| 	18.4 | 	873.0 | 	-17.7 | 	18.4 | 	0.9 | 	17.7 |
| 	-5.9 | 	3.1 | 	-1.6 | 	5.9 | 	3.1 | 	1.6 |
| 	-4.6 | 	2.2 | 	-150.1 | 	4.6 | 	2.2 | 	0.9 |
| 	-3.5 | 	1.7 | 	-284.1 | 	3.5 | 	1.7 | 	2.9 |
| 	-1.3 | 	-1.6 | 	-586.5 | 	1.3 | 	1.6 | 	2.5 |
| 	3.1 | 	-5.1 | 	-873.6 | 	3.1 | 	5.1 | 	1.5 |

### Results
| Method | Metric | Value |
|---|---|---|
| Least Squares Method | Mean Absolute Error | 5.164444444444446 g |
| Polynomial Regression Method | Mean Absolute Error | 4.413333333333333 g |
| Least Squares Method | Root Mean Square Error| 8.277653988634434 g |
| Polynomial Regression Method | Root Mean Square Error| 6.46020295518819 g |
## Least Squares Calibration Matrix:
| K_x | K_y | K_z |
|-----|-----|-----|
| -5.982118e-04 | -6.398772e-06 | 1.493637e-05 |
| -1.610696e-05 | 5.980800e-04 | 1.154983e-05 |
| 5.832123e-06 | -5.437381e-06 | 6.200539e-04 |

---
## Polynomial Regression Equations:
$$ F_x(R_x) = -4.779867e-12*R_x^0 + -6.139373e-04*R_x^1 + -2.828916e+02*R_x^2 $$
$$ F_y(R_y) = 1.063187e-11*R_y^0 + 5.951776e-04*R_y^1 + 3.592542e+02*R_y^2 $$
$$ F_z(R_z) = -9.493906e-12*R_z^0 + 6.244786e-04*R_z^1 + -5.722137e+02*R_z^2 $$

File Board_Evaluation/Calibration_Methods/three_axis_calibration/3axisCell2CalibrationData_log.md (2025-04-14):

### Estimated forces (gramsForce) and Absolute Errors using Least Squares Method:
| Calculated X | Calculated Y | Calculated Z | Error X | Error Y | Error Z |
|---|---|---|---|---|---|
| 	0.0 | 	0.0 | 	0.0 | 	0.0 | 	0.0 | 	0.0 |
| 	151.0 | 	3.5 | 	0.0 | 	0.0 | 	3.5 | 	0.0 |
| 	286.6 | 	6.4 | 	0.0 | 	0.4 | 	6.4 | 	0.0 |
| 	588.9 | 	13.2 | 	-0.5 | 	0.1 | 	13.2 | 	0.5 |
| 	871.7 | 	19.5 | 	-3.6 | 	0.4 | 	19.5 | 	3.6 |
| 	0.0 | 	0.0 | 	0.0 | 	0.0 | 	0.0 | 	0.0 |
| 	-3.8 | 	150.9 | 	2.1 | 	3.8 | 	0.1 | 	2.1 |
| 	-6.8 | 	286.6 | 	2.6 | 	6.8 | 	0.4 | 	2.6 |
| 	-12.8 | 	589.0 | 	9.5 | 	12.8 | 	0.0 | 	9.5 |
| 	-20.0 | 	872.3 | 	9.8 | 	20.0 | 	0.2 | 	9.8 |
| 	0.0 | 	0.0 | 	0.0 | 	0.0 | 	0.0 | 	0.0 |
| 	-0.3 | 	2.0 | 	-151.0 | 	0.3 | 	2.0 | 	0.0 |
| 	-0.9 | 	3.6 | 	-286.6 | 	0.9 | 	3.6 | 	0.4 |
| 	-1.3 | 	7.2 | 	-588.9 | 	1.3 | 	7.2 | 	0.1 |
| 	-3.7 | 	11.0 | 	-871.9 | 	3.7 | 	11.0 | 	0.2 |

### Estimated forces (gramsForce) and Absolute Errors using Polynomial Regression Method:
| Calculated X | Calculated Y | Calculated Z | Error  X | Error Y | Error Z |
|---|---|---|---|---|---|
| 	-0.9 | 	-6.9 | 	3.8 | 	0.9 | 	6.9 | 	3.8 |
| 	150.6 | 	-4.0 | 	2.3 | 	0.4 | 	4.0 | 	2.3 |
| 	286.4 | 	-1.5 | 	0.8 | 	0.6 | 	1.5 | 	0.8 |
| 	589.2 | 	4.1 | 	-2.8 | 	0.2 | 	4.1 | 	2.8 |
| 	872.1 | 	9.4 | 	-9.0 | 	0.0 | 	9.4 | 	9.0 |
| 	-0.9 | 	-6.9 | 	3.8 | 	0.9 | 	6.9 | 	3.8 |
| 	-1.9 | 	147.5 | 	2.5 | 	1.9 | 	3.5 | 	2.5 |
| 	-2.5 | 	285.5 | 	-0.2 | 	2.5 | 	1.5 | 	0.2 |
| 	-2.9 | 	590.1 | 	-0.3 | 	2.9 | 	1.1 | 	0.3 |
| 	-4.9 | 	871.8 | 	-6.7 | 	4.9 | 	0.3 | 	6.7 |
| 	-0.9 | 	-6.9 | 	3.8 | 	0.9 | 	6.9 | 	3.8 |
| 	0.8 | 	-3.2 | 	-149.3 | 	0.8 | 	3.2 | 	1.7 |
| 	2.1 | 	-0.2 | 	-286.3 | 	2.1 | 	0.2 | 	0.7 |
| 	5.7 | 	6.7 | 	-589.8 | 	5.7 | 	6.7 | 	0.8 |
| 	7.1 | 	13.7 | 	-871.8 | 	7.1 | 	13.7 | 	0.3 |

### Results
| Method | Metric | Value |
|---|---|---|
| Least Squares Method | Mean Absolute Error | 3.253333333333332 g |
| Polynomial Regression Method | Mean Absolute Error | 3.1377777777777816 g |
| Least Squares Method | Root Mean Square Error| 6.0547869033058825 g |
| Polynomial Regression Method | Root Mean Square Error| 4.3502234936201205 g |
## Least Squares Calibration Matrix:
| K_x | K_y | K_z |
|-----|-----|-----|
| 5.981983e-04 | -1.070736e-05 | 7.760431e-06 |
| 2.589967e-06 | 5.869149e-04 | 6.217067e-06 |
| 5.954714e-06 | 1.355531e-05 | 5.982035e-04 |

---
## Polynomial Regression Equations:
$$ F_x(R_x) = -7.213967e-13*R_x^0 + 6.002052e-04*R_x^1 + -1.517346e+02*R_x^2 $$
$$ F_y(R_y) = -7.526178e-12*R_y^0 + 5.941050e-04*R_y^1 + 3.217731e+02*R_y^2 $$
$$ F_z(R_z) = 4.769434e-12*R_z^0 + 5.964100e-04*R_z^1 + -6.883740e+02*R_z^2 $$

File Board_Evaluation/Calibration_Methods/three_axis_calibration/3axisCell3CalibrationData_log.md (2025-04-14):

### Estimated forces (gramsForce) and Absolute Errors using Least Squares Method:
| Calculated X | Calculated Y | Calculated Z | Error X | Error Y | Error Z |
|---|---|---|---|---|---|
| 	0.0 | 	0.0 | 	0.0 | 	0.0 | 	0.0 | 	0.0 |
| 	151.0 | 	-0.1 | 	-5.3 | 	0.0 | 	0.1 | 	5.3 |
| 	286.9 | 	-0.4 | 	-8.9 | 	0.1 | 	0.4 | 	8.9 |
| 	588.7 | 	-1.1 | 	-19.0 | 	0.3 | 	1.1 | 	19.0 |
| 	871.6 | 	-2.0 | 	-26.3 | 	0.5 | 	2.0 | 	26.3 |
| 	0.0 | 	0.0 | 	0.0 | 	0.0 | 	0.0 | 	0.0 |
| 	0.4 | 	122.1 | 	-1.1 | 	0.4 | 	28.9 | 	1.1 |
| 	-0.5 | 	287.3 | 	-2.8 | 	0.5 | 	0.3 | 	2.8 |
| 	-1.2 | 	590.6 | 	-5.6 | 	1.2 | 	1.6 | 	5.6 |
| 	-1.8 | 	874.8 | 	-9.4 | 	1.8 | 	2.7 | 	9.4 |
| 	0.0 | 	0.0 | 	0.0 | 	0.0 | 	0.0 | 	0.0 |
| 	4.0 | 	-1.7 | 	151.1 | 	4.0 | 	1.7 | 	0.1 |
| 	9.0 | 	-2.8 | 	286.7 | 	9.0 | 	2.8 | 	0.3 |
| 	17.8 | 	-5.7 | 	588.9 | 	17.8 | 	5.7 | 	0.1 |
| 	29.4 | 	-8.7 | 	871.9 | 	29.4 | 	8.7 | 	0.2 |

### Estimated forces (gramsForce) and Absolute Errors using Polynomial Regression Method:
| Calculated X | Calculated Y | Calculated Z | Error  X | Error Y | Error Z |
|---|---|---|---|---|---|
| 	-5.8 | 	8.4 | 	1.8 | 	5.8 | 	8.4 | 	1.8 |
| 	148.1 | 	5.1 | 	-1.4 | 	2.9 | 	5.1 | 	1.4 |
| 	285.9 | 	2.0 | 	-3.1 | 	1.1 | 	2.0 | 	3.1 |
| 	589.8 | 	-5.0 | 	-9.1 | 	0.8 | 	5.0 | 	9.1 |
| 	871.9 | 	-12.0 | 	-12.6 | 	0.2 | 	12.0 | 	12.6 |
| 	-5.8 | 	8.4 | 	1.8 | 	5.8 | 	8.4 | 	1.8 |
| 	-2.5 | 	129.8 | 	2.9 | 	2.5 | 	21.2 | 	2.9 |
| 	0.5 | 	293.3 | 	4.2 | 	0.5 | 	6.3 | 	4.2 |
| 	7.1 | 	592.1 | 	6.9 | 	7.1 | 	3.1 | 	6.9 |
| 	13.3 | 	870.4 | 	8.2 | 	13.3 | 	1.7 | 	8.2 |
| 	-5.8 | 	8.4 | 	1.8 | 	5.8 | 	8.4 | 	1.8 |
| 	-4.5 | 	5.5 | 	151.2 | 	4.5 | 	5.5 | 	0.2 |
| 	-2.0 | 	3.1 | 	285.9 | 	2.0 | 	3.1 | 	1.1 |
| 	1.3 | 	-2.5 | 	587.8 | 	1.3 | 	2.5 | 	1.2 |
| 	7.8 | 	-8.0 | 	872.8 | 	7.8 | 	8.0 | 	0.7 |

### Results
| Method | Metric | Value |
|---|---|---|
| Least Squares Method | Mean Absolute Error | 4.446666666666667 g |
| Polynomial Regression Method | Mean Absolute Error | 4.868888888888891 g |
| Least Squares Method | Root Mean Square Error| 8.871915739505695 g |
| Polynomial Regression Method | Root Mean Square Error| 6.43112224524875 g |
## Least Squares Calibration Matrix:
| K_x | K_y | K_z |
|-----|-----|-----|
| -5.967505e-04 | -1.410111e-05 | -1.031143e-05 |
| -1.276690e-05 | 5.953475e-04 | -4.933627e-06 |
| 8.278846e-06 | -1.064470e-05 | -5.746296e-04 |

---
## Polynomial Regression Equations:
$$ F_x(R_x) = -5.842038e-12*R_x^0 + -6.000414e-04*R_x^1 + 4.924497e+02*R_x^2 $$
$$ F_y(R_y) = -3.809444e-12*R_y^0 + 5.873697e-04*R_y^1 + 4.065573e+02*R_y^2 $$
$$ F_z(R_z) = 4.556780e-12*R_z^0 + -5.611561e-04*R_z^1 + -3.722284e+02*R_z^2 $$

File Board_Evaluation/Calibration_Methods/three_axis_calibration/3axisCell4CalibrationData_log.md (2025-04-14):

### Estimated forces (gramsForce) and Absolute Errors using Least Squares Method:
| Calculated X | Calculated Y | Calculated Z | Error X | Error Y | Error Z |
|---|---|---|---|---|---|
| 	0.0 | 	0.0 | 	0.0 | 	0.0 | 	0.0 | 	0.0 |
| 	151.1 | 	0.6 | 	-2.3 | 	0.1 | 	0.6 | 	2.3 |
| 	287.0 | 	1.1 | 	-3.5 | 	0.0 | 	1.1 | 	3.5 |
| 	588.5 | 	2.6 | 	-6.7 | 	0.5 | 	2.6 | 	6.7 |
| 	872.4 | 	3.1 | 	-8.1 | 	0.3 | 	3.1 | 	8.1 |
| 	0.0 | 	0.0 | 	0.0 | 	0.0 | 	0.0 | 	0.0 |
| 	0.4 | 	151.0 | 	-3.5 | 	0.4 | 	0.0 | 	3.5 |
| 	1.1 | 	286.5 | 	-6.8 | 	1.1 | 	0.5 | 	6.8 |
| 	2.3 | 	589.0 | 	-13.1 | 	2.3 | 	0.0 | 	13.1 |
| 	3.6 | 	872.1 | 	-17.4 | 	3.6 | 	0.0 | 	17.4 |
| 	0.0 | 	0.0 | 	0.0 | 	0.0 | 	0.0 | 	0.0 |
| 	-1.9 | 	3.5 | 	150.6 | 	1.9 | 	3.5 | 	0.4 |
| 	-3.6 | 	5.7 | 	288.2 | 	3.6 | 	5.7 | 	1.2 |
| 	-6.2 | 	12.0 | 	589.2 | 	6.2 | 	12.0 | 	0.2 |
| 	-8.6 | 	17.4 | 	871.4 | 	8.6 | 	17.4 | 	0.7 |

### Estimated forces (gramsForce) and Absolute Errors using Polynomial Regression Method:
| Calculated X | Calculated Y | Calculated Z | Error  X | Error Y | Error Z |
|---|---|---|---|---|---|
| 	-2.4 | 	1.3 | 	2.4 | 	2.4 | 	1.3 | 	2.4 |
| 	149.4 | 	-1.4 | 	1.1 | 	1.6 | 	1.4 | 	1.1 |
| 	285.8 | 	-3.9 | 	0.7 | 	1.2 | 	3.9 | 	0.7 |
| 	588.2 | 	-9.0 | 	-0.6 | 	0.8 | 	9.0 | 	0.6 |
| 	872.6 | 	-14.7 | 	-0.1 | 	0.5 | 	14.7 | 	0.1 |
| 	-2.4 | 	1.3 | 	2.4 | 	2.4 | 	1.3 | 	2.4 |
| 	0.8 | 	150.8 | 	0.7 | 	0.8 | 	0.2 | 	0.7 |
| 	3.9 | 	285.5 | 	-1.0 | 	3.9 | 	1.5 | 	1.0 |
| 	10.7 | 	587.7 | 	-3.6 | 	10.7 | 	1.3 | 	3.6 |
| 	17.2 | 	872.8 | 	-4.5 | 	17.2 | 	0.7 | 	4.5 |
| 	-2.4 | 	1.3 | 	2.4 | 	2.4 | 	1.3 | 	2.4 |
| 	-3.7 | 	3.5 | 	151.1 | 	3.7 | 	3.5 | 	0.1 |
| 	-4.9 | 	4.5 | 	287.5 | 	4.9 | 	4.5 | 	0.5 |
| 	-6.2 | 	8.2 | 	588.1 | 	6.2 | 	8.2 | 	0.9 |
| 	-7.5 | 	11.1 | 	872.4 | 	7.5 | 	11.1 | 	0.3 |

### Results
| Method | Metric | Value |
|---|---|---|
| Least Squares Method | Mean Absolute Error | 3.08888888888889 g |
| Polynomial Regression Method | Mean Absolute Error | 3.364444444444439 g |
| Least Squares Method | Root Mean Square Error| 5.419430064335383 g |
| Polynomial Regression Method | Root Mean Square Error| 5.126618985473975 g |
## Least Squares Calibration Matrix:
| K_x | K_y | K_z |
|-----|-----|-----|
| -6.007485e-04 | -1.092638e-05 | -2.390023e-06 |
| -1.328377e-05 | 5.968730e-04 | 5.299463e-06 |
| 3.958772e-06 | -7.053156e-06 | 6.141198e-04 |

---
## Polynomial Regression Equations:
$$ F_x(R_x) = -8.463602e-13*R_x^0 + -6.040589e-04*R_x^1 + -1.973620e+01*R_x^2 $$
$$ F_y(R_y) = 4.519417e-12*R_y^0 + 5.982422e-04*R_y^1 + 5.351286e+02*R_y^2 $$
$$ F_z(R_z) = 5.869018e-12*R_z^0 + 5.996329e-04*R_z^1 + -2.636953e+02*R_z^2 $$

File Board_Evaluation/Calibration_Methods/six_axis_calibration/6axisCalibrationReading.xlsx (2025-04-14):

force on the y axis |  |  |  |  |  |  |  |  | Fx | Fy | Fz | Mx | My | Mz | known_Fx | known_Fy | known_Fz | Known_Mx | Known_My | known_Mz
Fx | Fy | Fz | Mx | My | Mz | Weight (g) | Expected Fy (N) |  | -0.026 | -0.049 | 0.013 | 0.001 | 0.002 | 0.002 | 0 | 0 | 0 | 0 | 0 | 0 |  |  |  | 0.107 | 3.91 | -0.074 | -0.093 | 0 | -0.022 | 400 | 3.924
-0.026 | -0.049 | 0.013 | 0.001 | 0.002 | 0.002 | 0 | 0 |  | -0.006 | 0.563 | 0 | -0.01 | 0.002 | -0.002 | 0 | 0.5886 | 0 | 0 | 0 | 0 |  |  |  | 0.18 | 6.731 | -0.129 | -0.156 | 0 | -0.037 | 685 | 6.71985
-0.006 | 0.563 | 0 | -0.01 | 0.002 | -0.002 | 60 | 0.5886 |  | 0.042 | 2.04 | -0.031 | -0.045 | 0.002 | -0.011 | 0 | 2.01105 | 0 | 0 | 0 | 0
0.042 | 2.04 | -0.031 | -0.045 | 0.002 | -0.011 | 205 | 2.01105 |  | 0.015 | 1.43 | -0.018 | -0.029 | 0.001 | -0.002 | 0 | 1.42245 | 0 | 0 | 0 | 0 |  |  |  | 0.147 | 3.869 | -0.336 | -1.04 | 0.016 | -0.06 | 400 | 3.924
0.015 | 1.43 | -0.018 | -0.029 | 0.001 | -0.002 | 145 | 1.42245 |  | 0.055 | 2.772 | -0.048 | -0.059 | 0 | -0.002 | 0 | 2.79585 | 0 | 0 | 0 | 0 |  |  |  | 0.092 | 6.633 | -0.227 | -0.61 | 0.008 | -0.038 | 685 | 6.71985
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

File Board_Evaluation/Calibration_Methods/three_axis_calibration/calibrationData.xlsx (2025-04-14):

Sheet: 3axis_1
force_x | force_y | force_z | sensor_x | sensor_y | sensor_z | corrected_x | corrected_y | corrected_z | orientation | load on x | load on y | load on z | reading on x | reading on y | reading on z | compensate for orientation x | y | z
0 | 0 | 0 | -591350 | -608700 | 731000 | -452825 | -604950 | 926820 | z up | 0 | 0 | 0 | -452825 | -604950 | 926820
151 | 0 | 0 | -844100 | -611800 | 737500 | -705575 | -608050 | 933320 | sideways align to x | 0 | 0 | 0 | -591350 | -608700 | 731000 | 138525 | 3750 | 195820
287 | 0 | 0 | -1070800 | -614000 | 744100 | -932275 | -610250 | 939920 | sideways align to y | 0 | 0 | 0 | -450200 | -517200 | 717100 | -2625 | -87750 | 209720
589 | 0 | 0 | -1575700 | -618700 | 755400 | -1437175 | -614950 | 951220 | z down | 0 | 0 | 0 | -450340 | -607240 | 529500 | -2485 | 2290 | 397320
872.1 | 0 | 0 | -2048200 | -624000 | 765500 | -1909675 | -620250 | 961320
0 | 0 | 0 | -450200 | -517200 | 717100 | -452825 | -604950 | 926820
0 | 151 | 0 | -456000 | -262000 | 712300 | -458625 | -349750 | 922020
0 | 287 | 0 | -462600 | -32800 | 707400 | -465225 | -120550 | 917120
0 | 589 | 0 | -477000 | 467500 | 700600 | -479625 | 379750 | 910320
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

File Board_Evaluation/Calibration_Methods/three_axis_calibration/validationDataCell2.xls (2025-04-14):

force_x | force_y | force_z | sensor_x | sensor_y | sensor_z | corrected_x | corrected_y | corrected_z
0 | 0 | 0 | 110700 | -550610 | 945480 | 243260 | -550040 | 1147140 | z up | 0 | 0 | 0 | 243260 | -550040 | 1147140
-61 | 0 | 0 | 6630 | -551160 | 944220 | 139190 | -550590 | 1145880 | z down | 0 | 0 | 0 | 252760 | -548360 | 745960 | 9500 | 1680 | -401180
-283 | 0 | 0 | -367550 | -548700 | 938360 | -234990 | -548130 | 1140020 | align to x | 0 | 0 | 0 | 110700 | -550610 | 945480 | -132560 | -570 | -201660
-465 | 0 | 0 | -672200 | -547260 | 932650 | -539640 | -546690 | 1134310 | align to y | 0 | 0 | 0 | 247920 | -467770 | 943700 | 4660 | 82270 | -203440
-1054 | 0 | 0 | -1663480 | -544000 | 911180 | -1530920 | -543430 | 1112840
-1926 | 0 | 0 | -3130950 | -540200 | 868050 | -2998390 | -539630 | 1069710
0 | 0 | 0 | 247920 | -467770 | 943700 | 243260 | -550040 | 1147140
0 | 61 | 0 | 248210 | -361760 | 942420 | 243550 | -444030 | 1145860
0 | 283 | 0 | 249160 | 18420 | 936940 | 244500 | -63850 | 1140380
0 | 465 | 0 | 249800 | 327920 | 931900 | 245140 | 245650 | 1135340
0 | 1054 | 0 | 250560 | 1338140 | 922500 | 245900 | 1255870 | 1125940
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

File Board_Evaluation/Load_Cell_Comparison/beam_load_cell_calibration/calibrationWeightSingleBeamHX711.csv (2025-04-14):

Weight | Reading
-1500.52 | -549260
-1056.84 | -429255
-620.06 | -311360
-586.93 | -302330
-443.68 | -263680
-401.45 | -252230
-286.1 | -221150
-150.15 | -184400
0 | -143690
150.15 | -95650
286.1 | -58900
401.45 | -27815
443.68 | -16350
586.93 | 22310
620.06 | 31250
1056.84 | 149240
1500.52 | 269250

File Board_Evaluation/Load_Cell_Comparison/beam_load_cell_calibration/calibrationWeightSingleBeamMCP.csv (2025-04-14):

Weight | Reading
-1500.52 | -1591000
-1056.84 | -858400
-620.06 | -137700
-586.93 | -83700
-443.68 | 147600
-401.45 | 229400
-286.1 | 417900
-150.15 | 639900
0 | 877900
150.15 | 1149800
286.1 | 1377400
401.45 | 1565900
443.68 | 1637100
586.93 | 1868400
620.06 | 1925700
1056.84 | 2645200
1500.52 | 3379500
1901.97 | 4045800

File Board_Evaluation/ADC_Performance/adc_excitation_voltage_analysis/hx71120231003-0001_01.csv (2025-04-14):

Time | Channel A
(ms) | (V)
-500.01996756 | 4.30036300
-500.00996756 | 4.28693500
-499.99996756 | 4.29776900
-499.98996756 | 4.30112600
-499.97996756 | 4.28846100
-499.96996756 | 4.29410700
-499.95996756 | 4.30478800
-499.94996756 | 4.29532800
-499.93996756 | 4.31043400
-499.92996756 | 4.31455400
-499.91996756 | 4.30768800
-499.90996756 | 4.30463600
-499.89996756 | 4.30616200
-499.88996756 | 4.30265200
-499.87996756 | 4.28876600
-499.86996756 | 4.30997700
-499.85996756 | 4.28540900
-499.84996756 | 4.31180800
-499.83996756 | 4.30234700
-499.82996756 | 4.29883700
-499.81996756 | 4.31455400
-499.80996756 | 4.29914200
-499.79996756 | 4.31196000
-499.78996756 | 4.30402500
-499.77996756 | 4.30997700
-499.76996756 | 4.30768800
-499.75996756 | 4.30906100
-499.74996756 | 4.30448300
-499.73996756 | 4.31775900
-499.72996756 | 4.30082100
-499.71996756 | 4.30677200
-499.70996756 | 4.30402500
-499.69996756 | 4.29792200
-499.68996756 | 4.29639600
-499.67996756 | 4.30600900
-499.66996756 | 4.31440200
-499.65996757 | 4.30219400
-499.64996757 | 4.31074000
-499.63996757 | 4.29548000
-499.62996757 | 4.29364900
-499.61996757 | 4.30372000
-499.60996757 | 4.29212300
-499.59996757 | 4.30036300
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

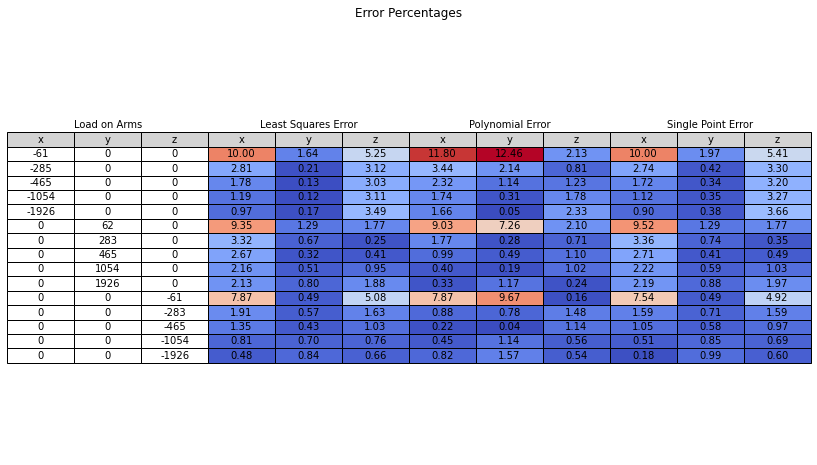
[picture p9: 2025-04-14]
Board_Evaluation/Calibration_Methods/three_axis_calibration/errorpercentage.png

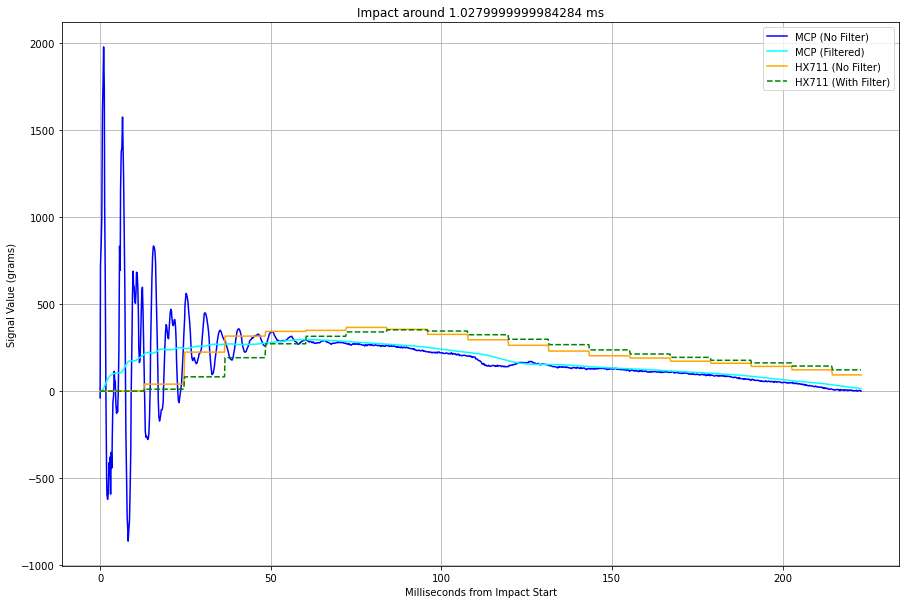
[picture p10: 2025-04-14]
Board_Evaluation/Load_Cell_Comparison/hx711_vs_mcp3564_comparison_v1/impulseSignal.png

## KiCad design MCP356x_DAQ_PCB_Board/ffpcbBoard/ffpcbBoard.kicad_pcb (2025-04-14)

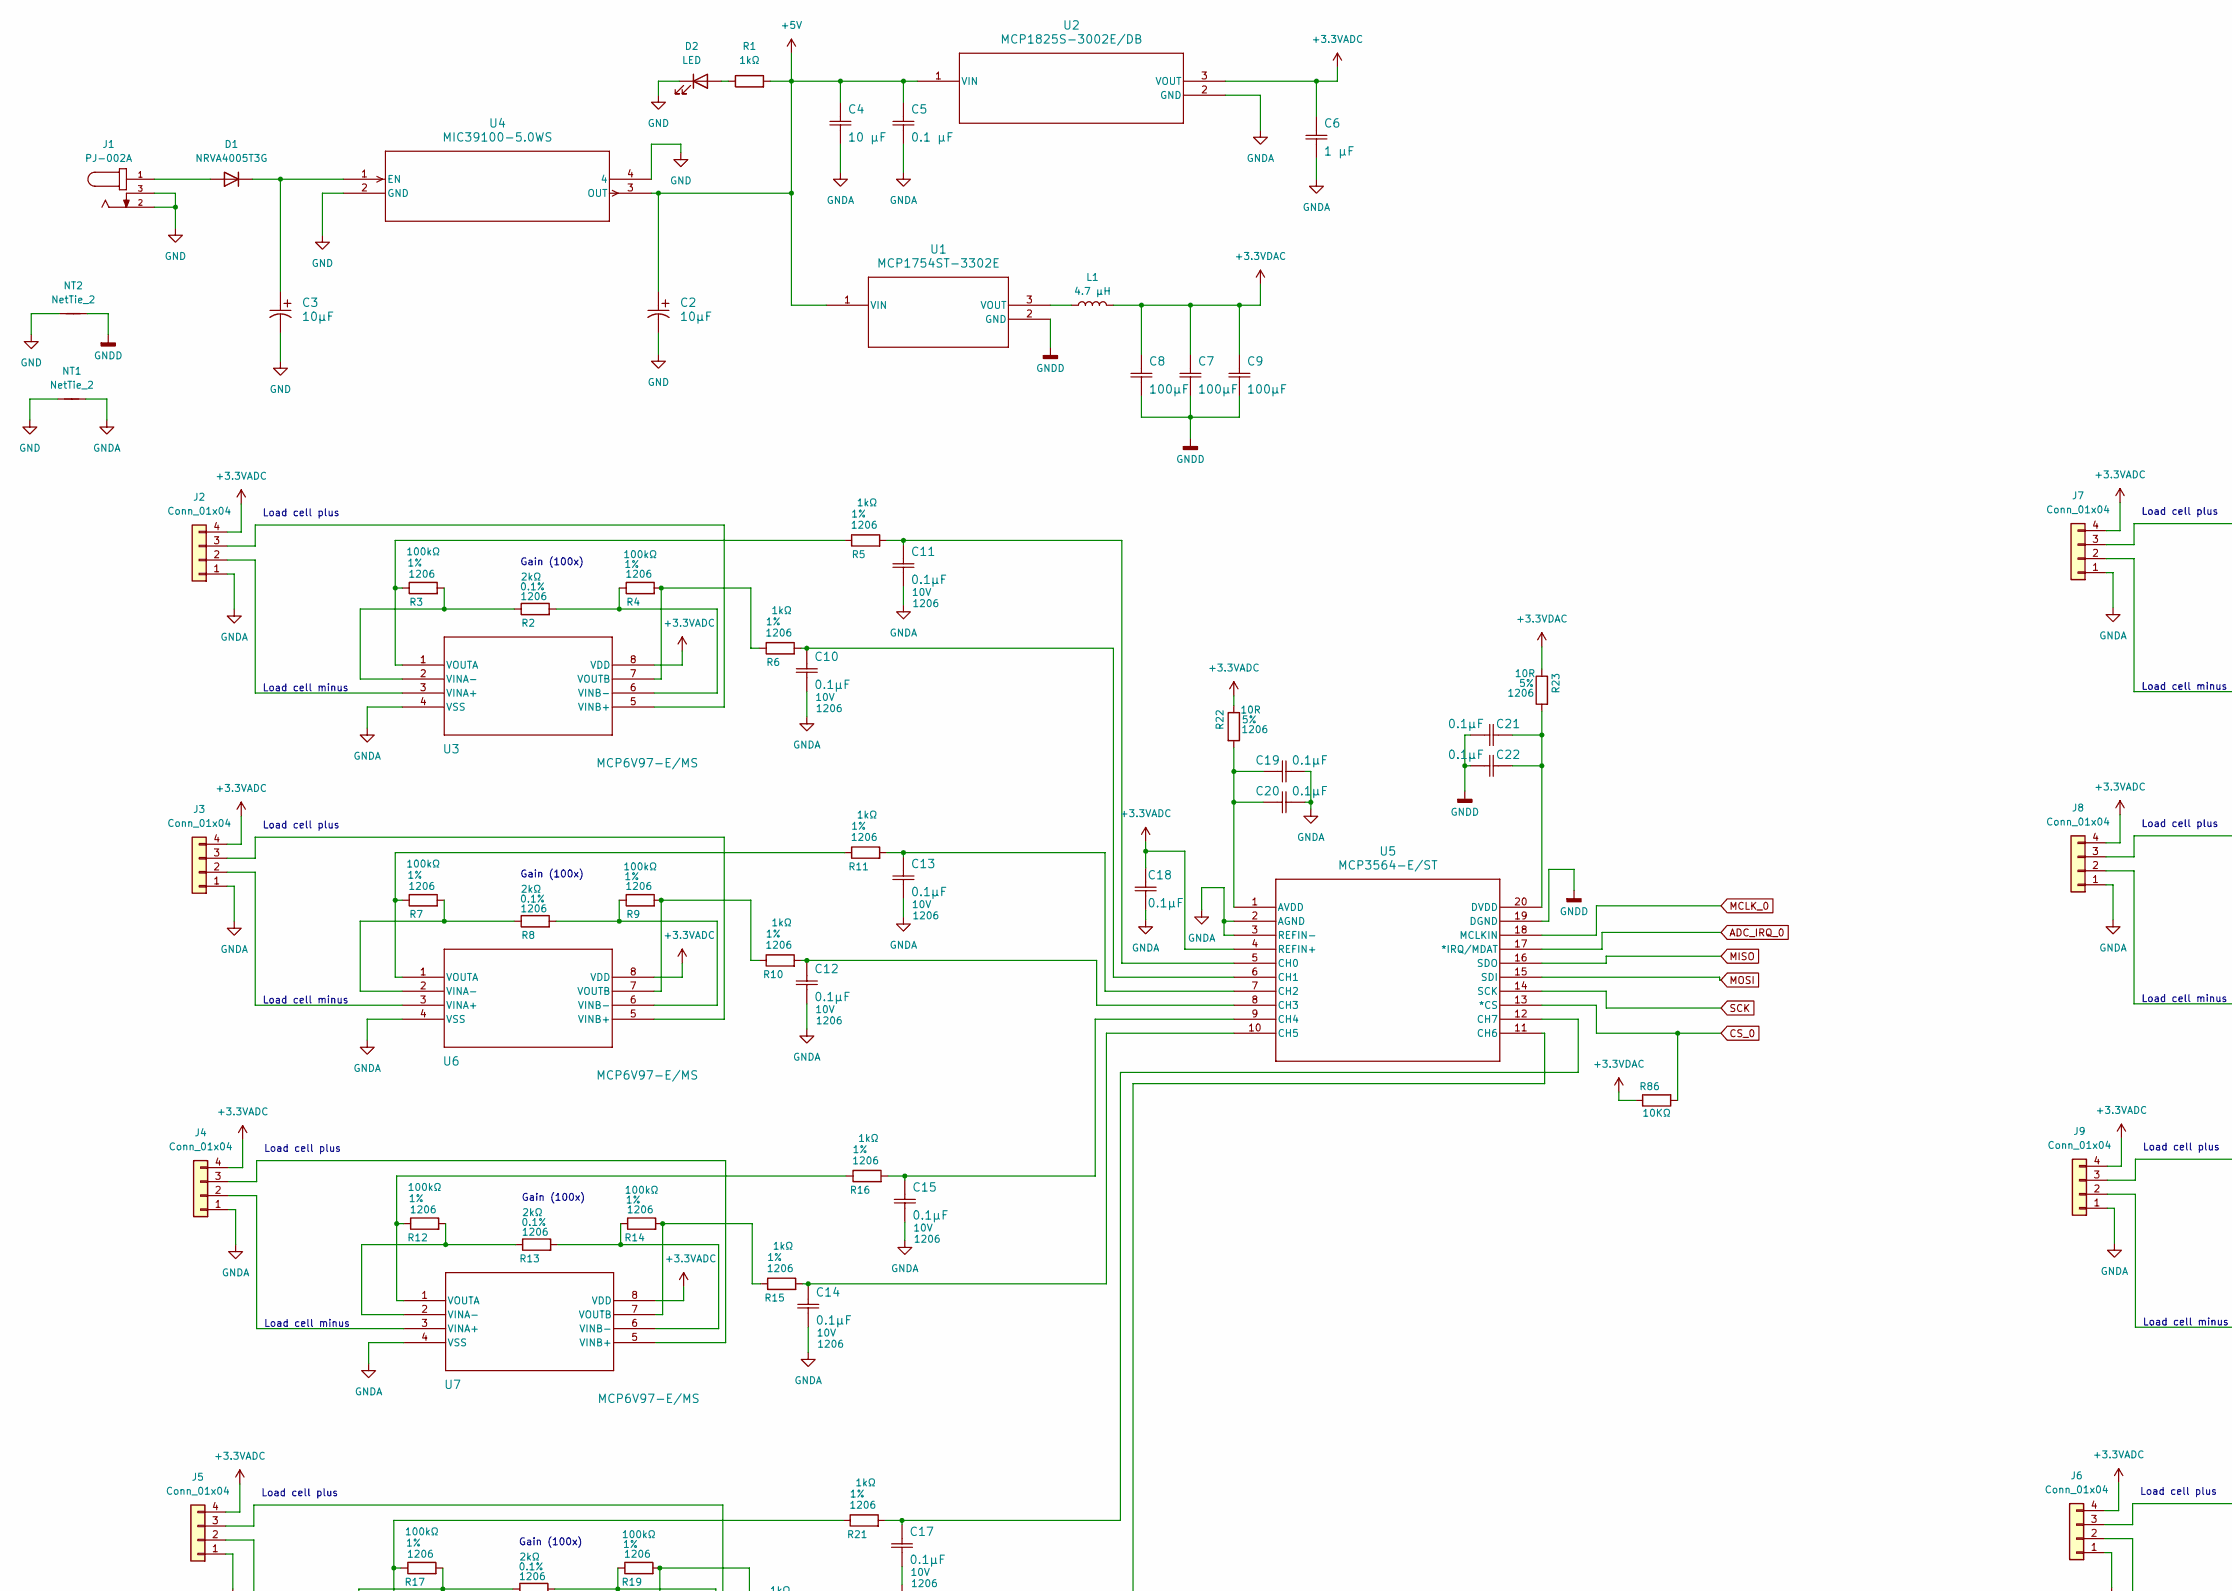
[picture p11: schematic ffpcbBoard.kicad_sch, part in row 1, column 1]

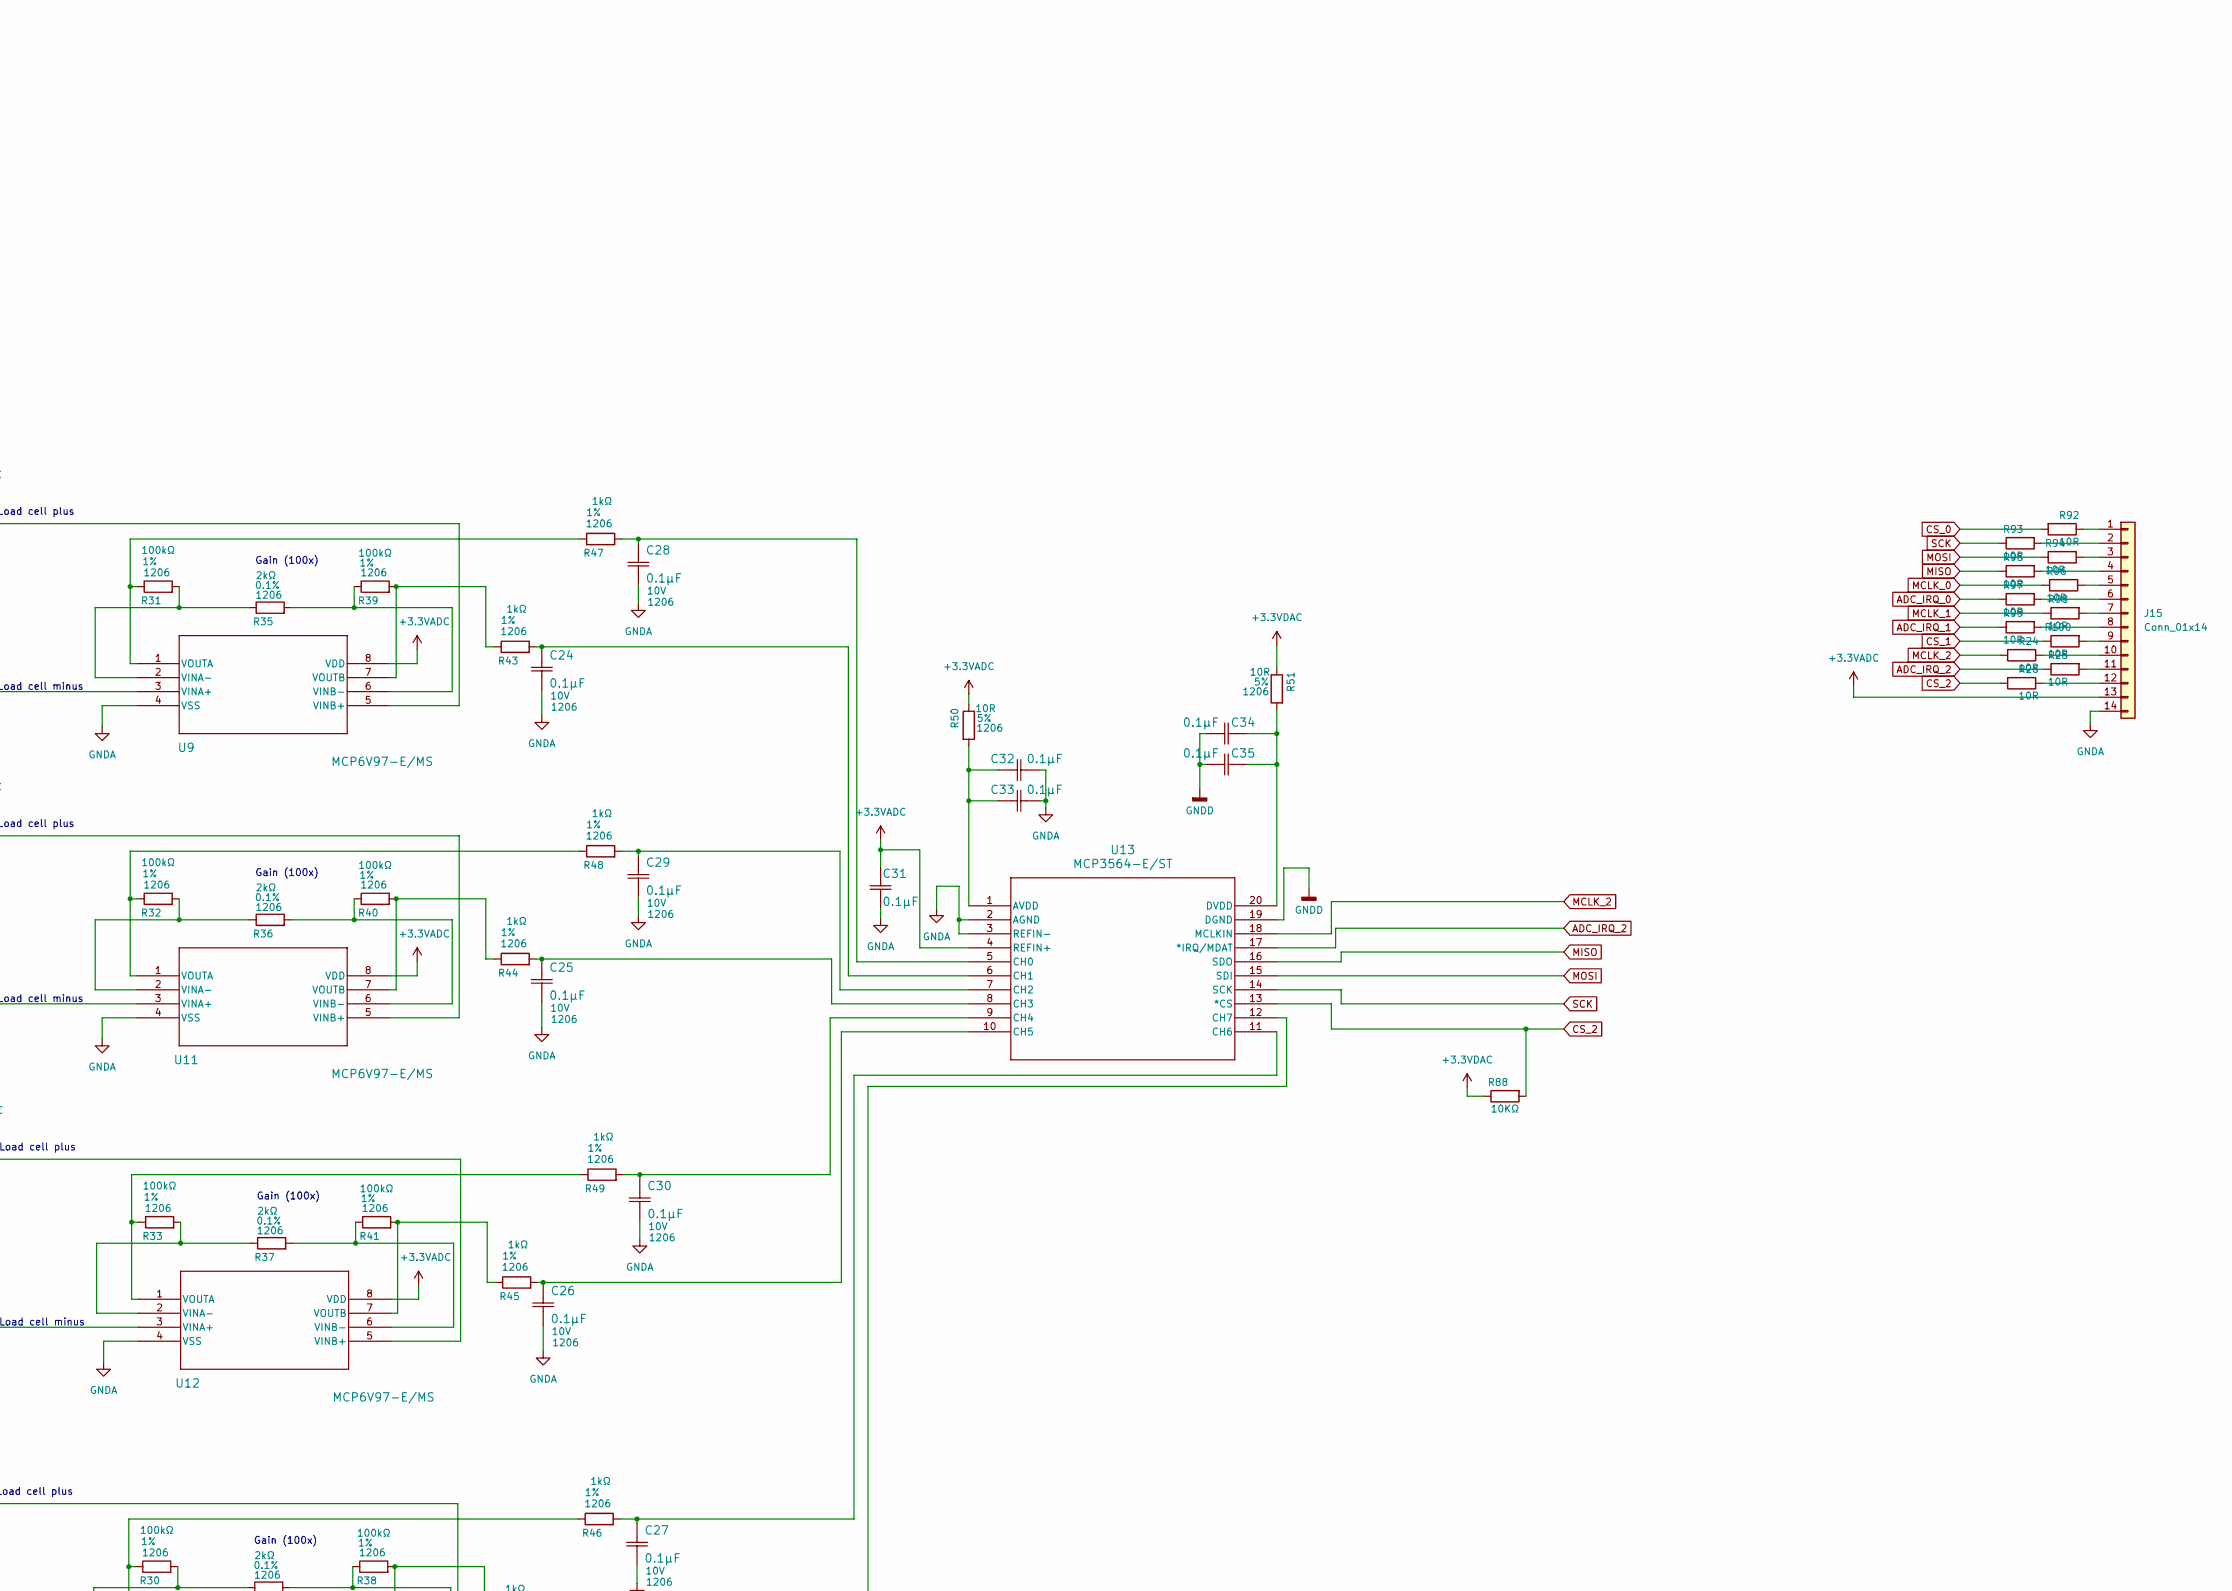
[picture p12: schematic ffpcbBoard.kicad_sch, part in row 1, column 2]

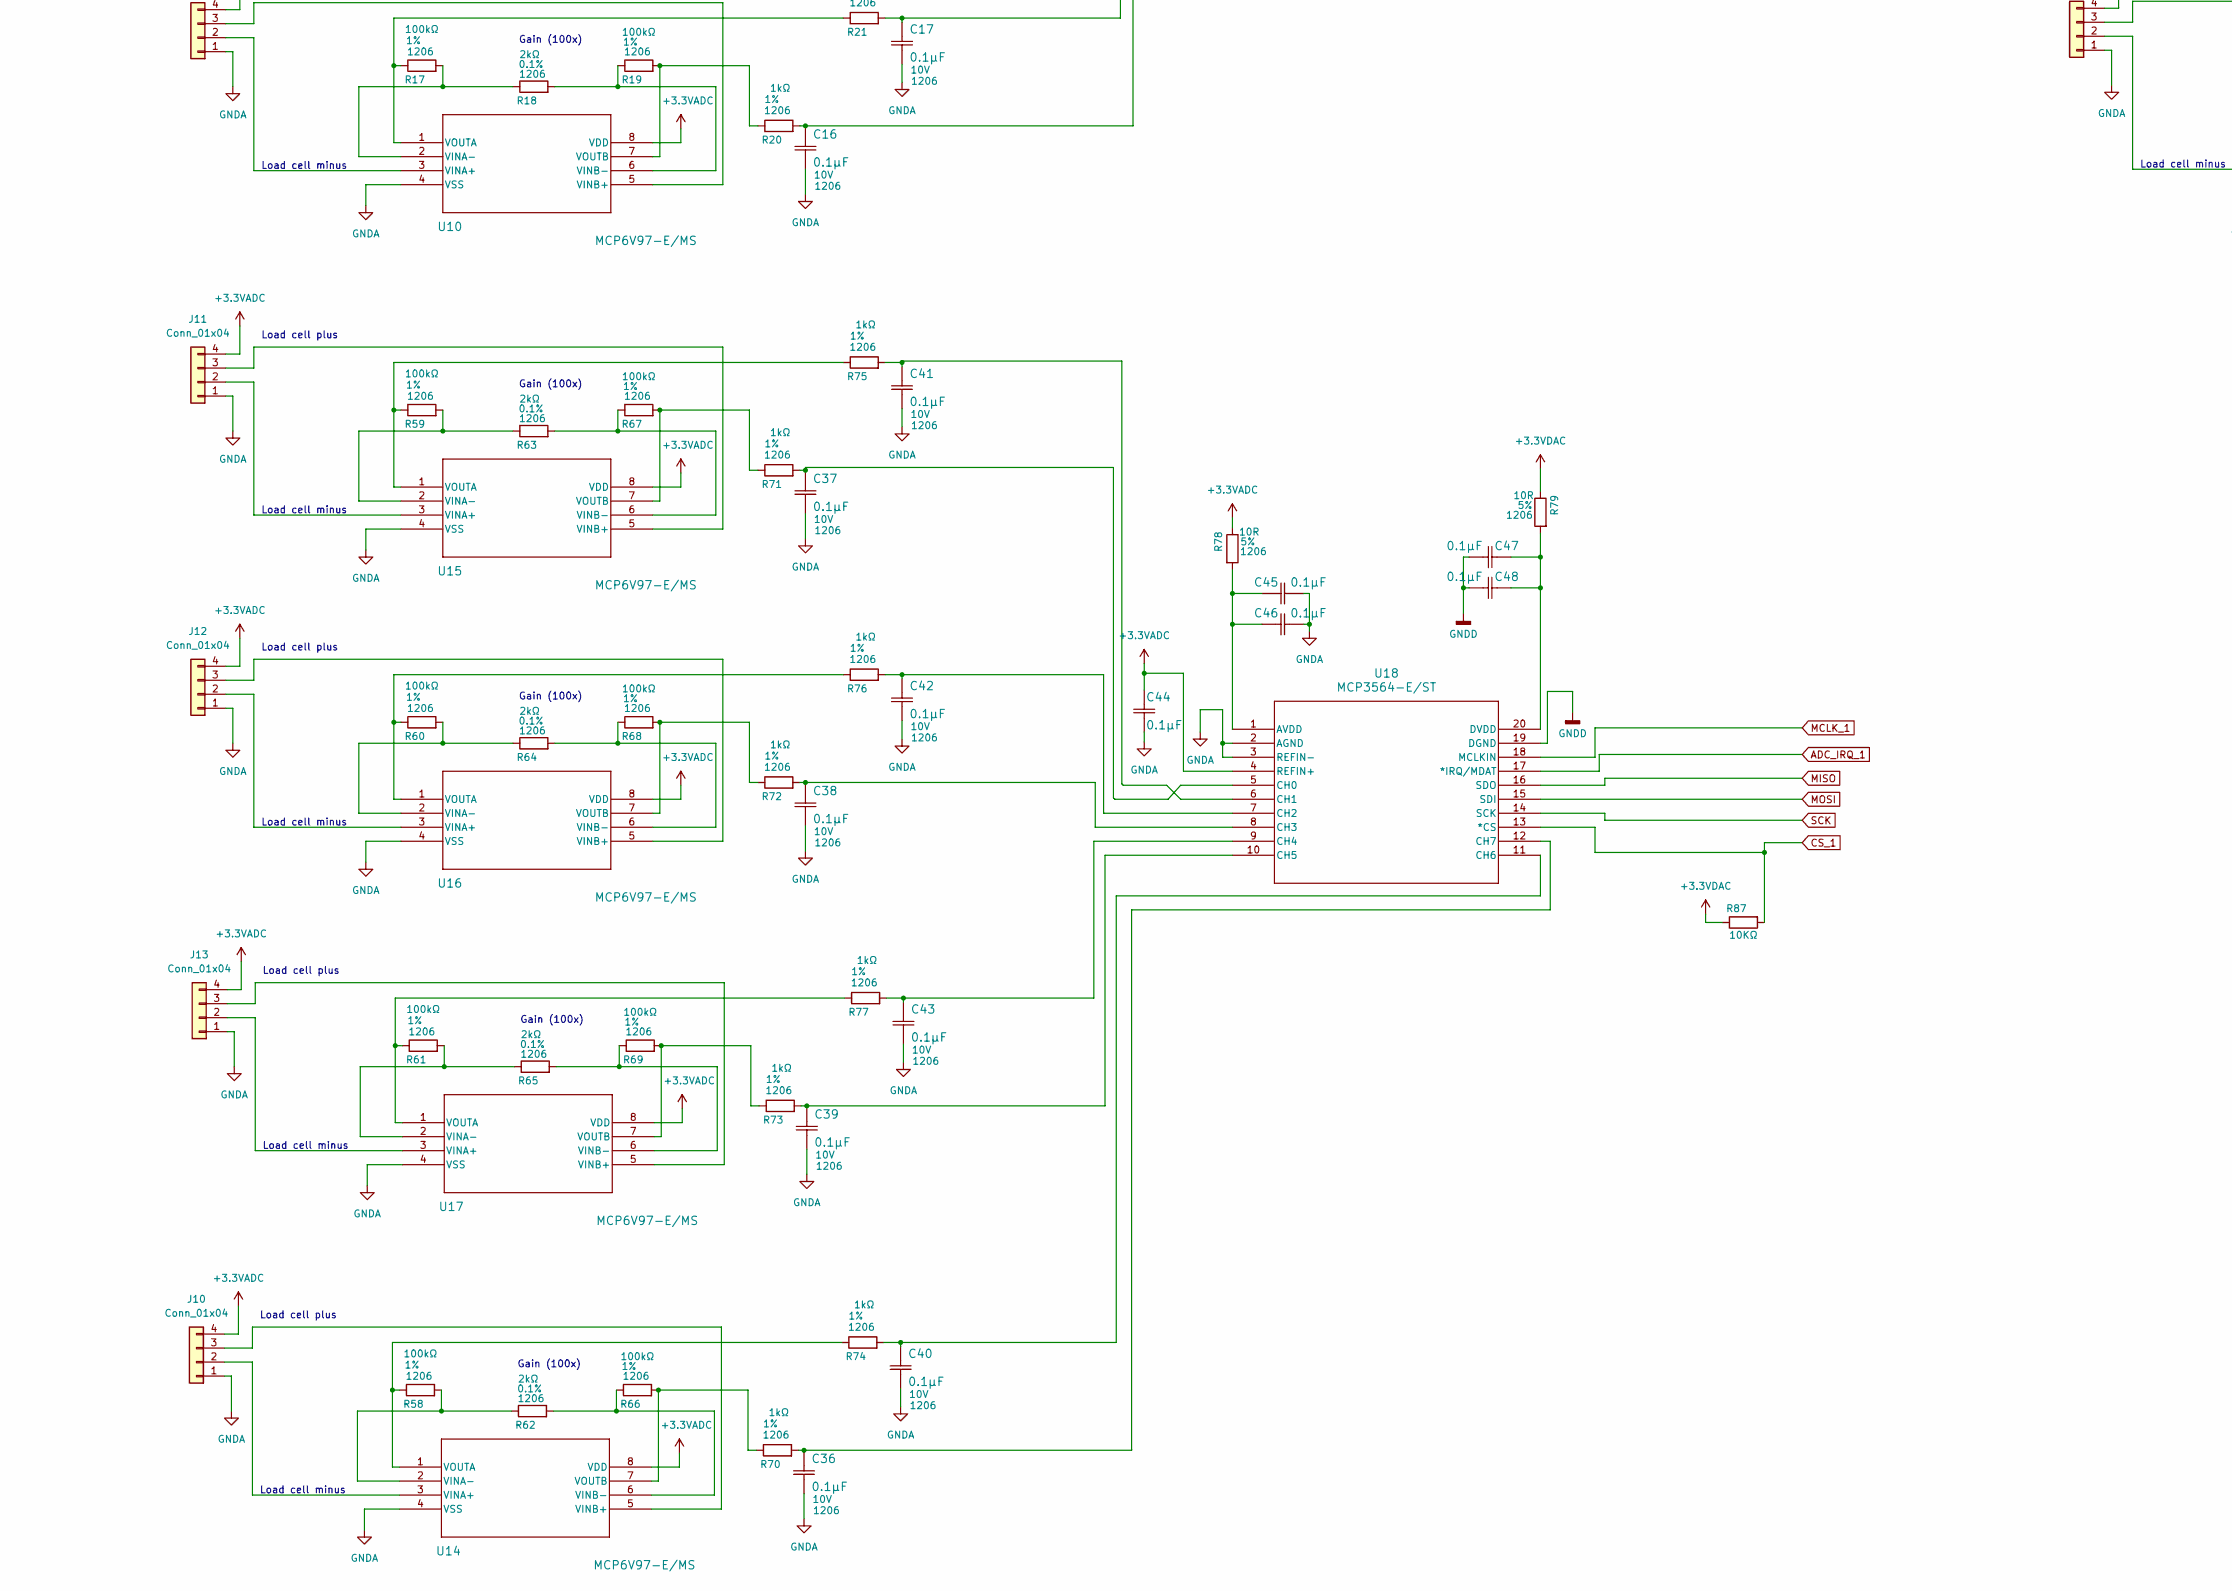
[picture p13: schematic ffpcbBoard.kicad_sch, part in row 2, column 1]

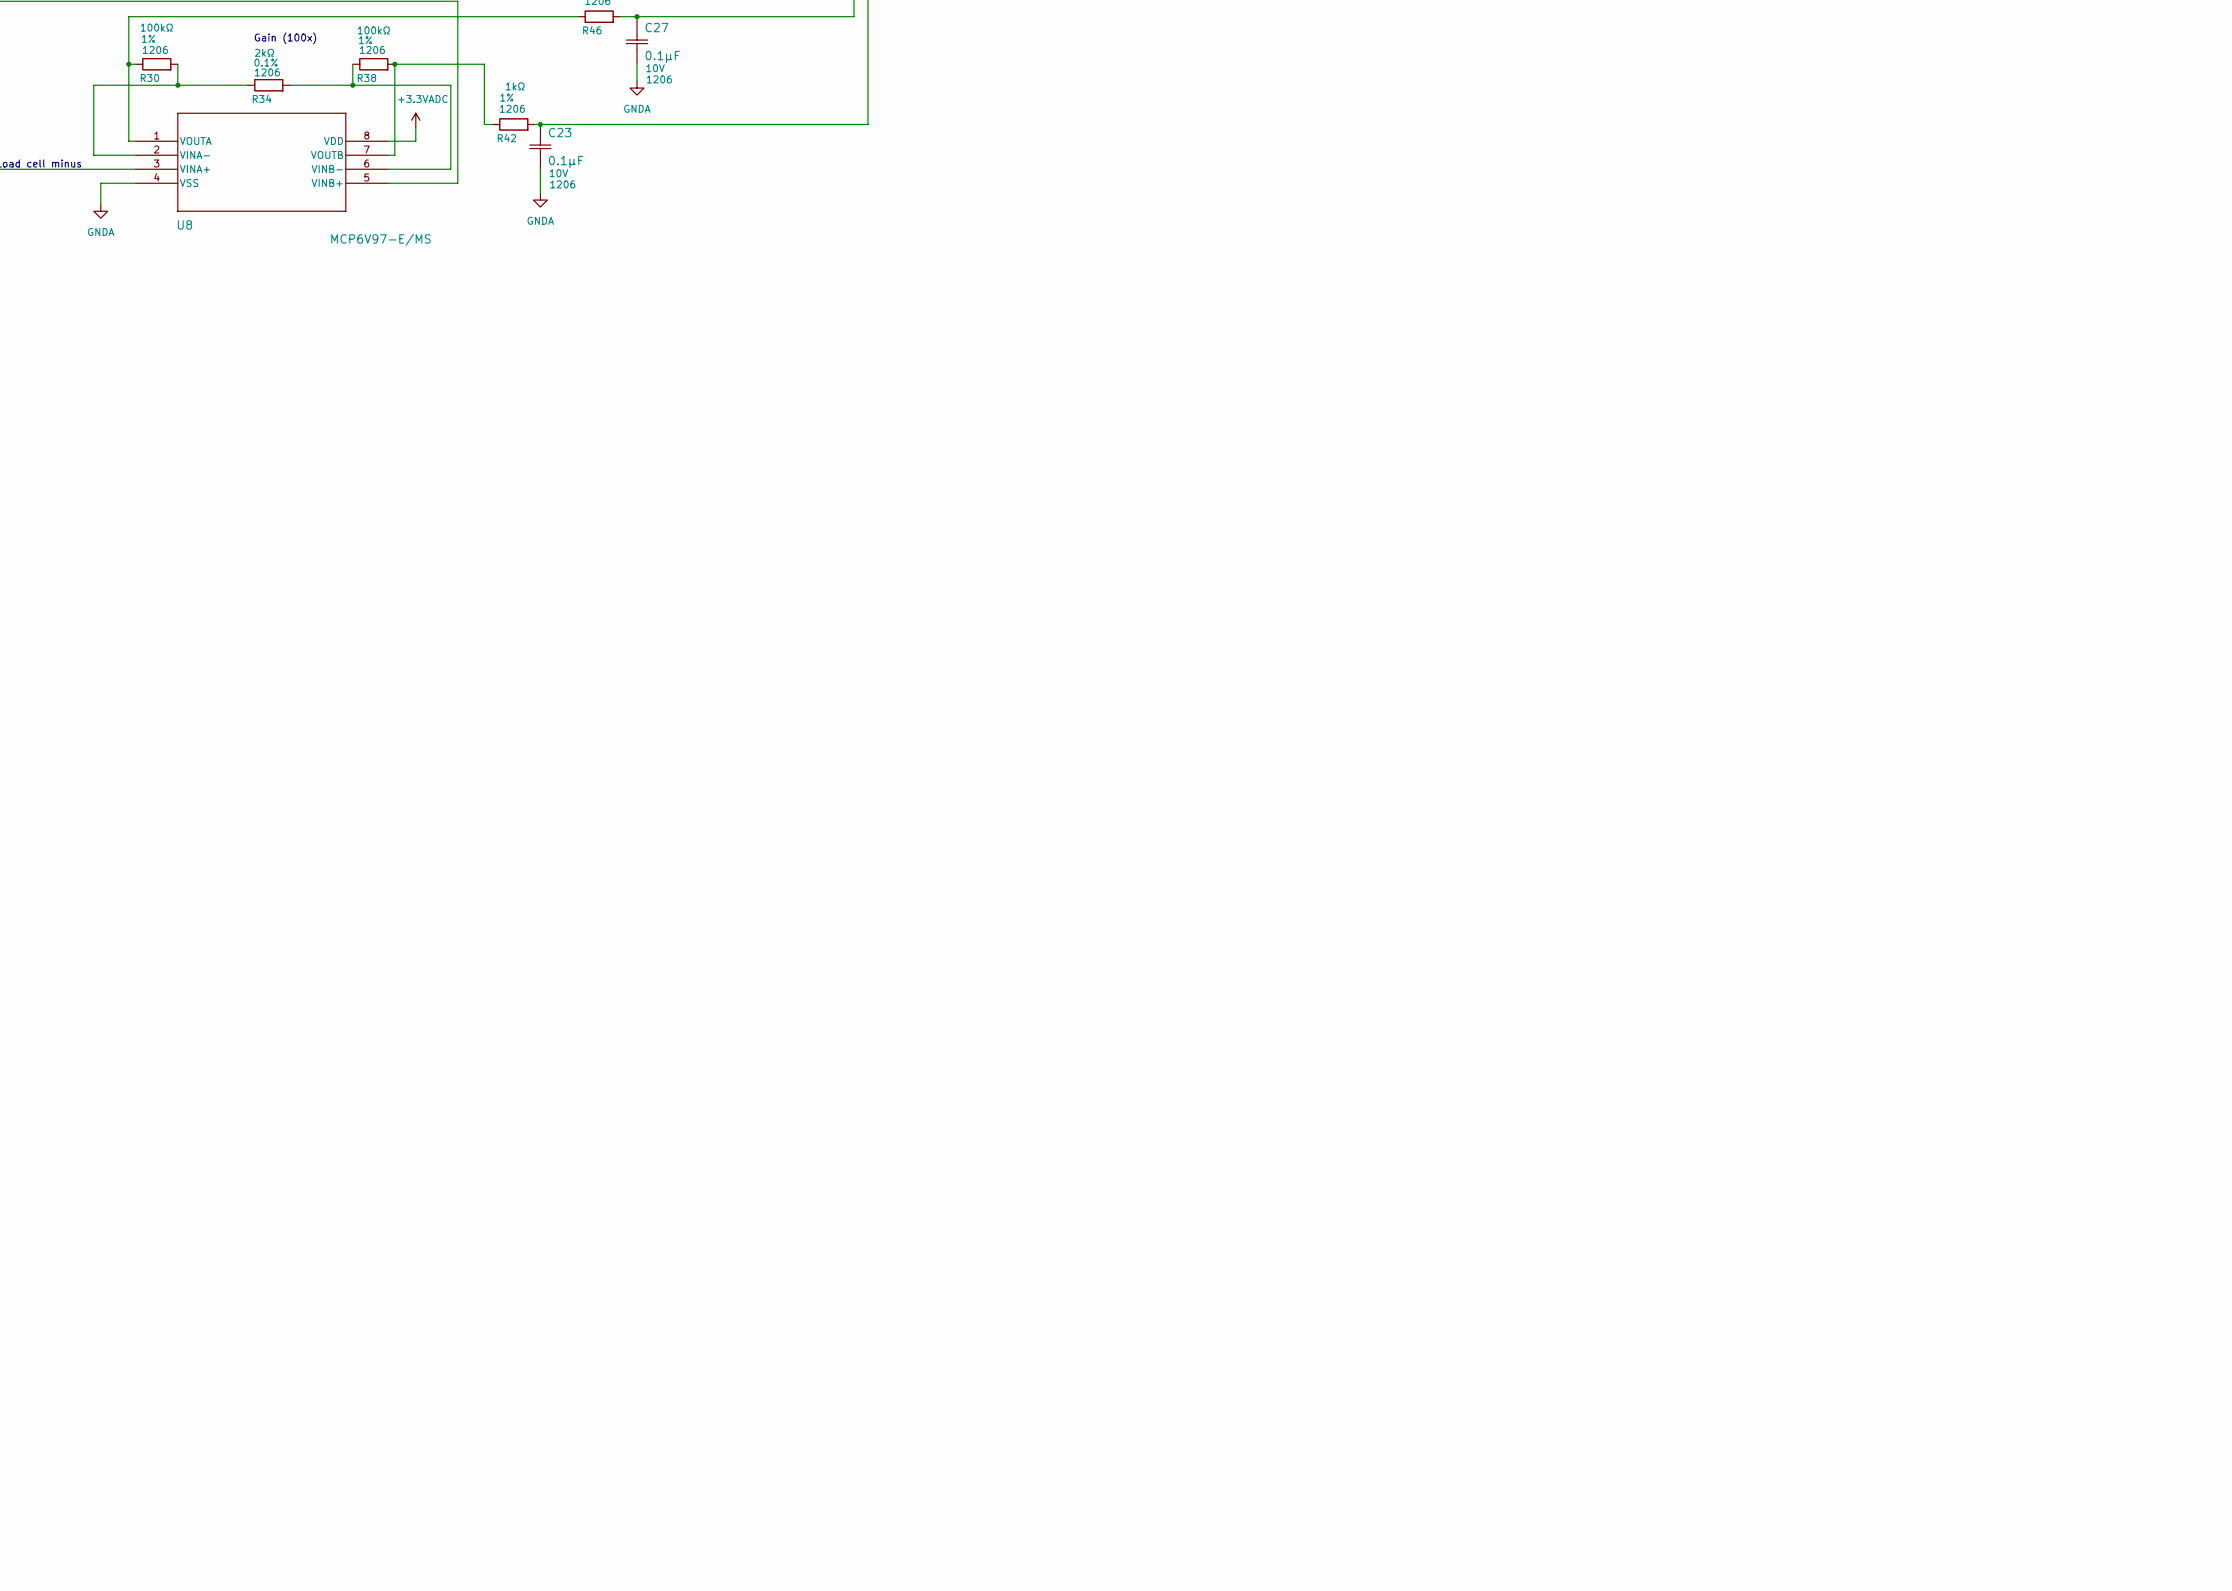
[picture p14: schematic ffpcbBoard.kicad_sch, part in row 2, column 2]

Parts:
C2, C3: 10µF; TAJB_AVX-M
C4: 10 µF; CAPC340180_180N_KEM-M
C5: 0.1 µF; CAPC340180_180N_KEM-M
C6: 1 µF; CAPC340180_180N_KEM-M
C7, C8, C9: 100µF; CAPC340180_180N_KEM-M
C10, C11, C12, C13, C14, C15, C16, C17, C18, C19, C20, C21, C22, C23, C24, C25, C26, C27, C28, C29, C30, C31, C32, C33, C34, C35, C36, C37, C38, C39, C40, C41, C42, C43, C44, C45, C46, C47, C48: 0.1µF; CAPC340180_180N_KEM-M
D1: NRVA4005T3G; D_SMA
D2: LED; LED_1206_3216Metric
J1: PJ-002A; CUI_PJ-002A
J2, J3, J4, J5, J6, J7, J8, J9, J10, J11, J12, J13: Conn_01x04; FanPinHeader_1x04_P2.54mm_Vertical
J15: Conn_01x14; PinSocket_1x14_P2.54mm_Vertical
L1: 4.7 µH; L_1206_3216Metric_Pad1.22x1.90mm_HandSolder
NT1, NT2: NetTie_2; NetTie-2_SMD_Pad0.5mm
R1, R5, R6, R10, R11, R15, R16, R20, R21, R42, R43, R44, R45, R46, R47, R48, R49, R70, R71, R72, R73, R74, R75, R76, R77: 1kΩ; R_1206_3216Metric_Pad1.30x1.75mm_HandSolder
R2, R8, R13, R18, R34, R35, R36, R37, R62, R63, R64, R65: 2kΩ; R_1206_3216Metric_Pad1.30x1.75mm_HandSolder
R3, R4, R7, R9, R12, R14, R17, R19, R30, R31, R32, R33, R38, R39, R40, R41, R58, R59, R60, R61, R66, R67, R68, R69: 100kΩ; R_1206_3216Metric_Pad1.30x1.75mm_HandSolder
R22, R23, R24, R25, R26, R50, R51, R78, R79, R92, R93, R94, R95, R96, R97, R98, R99, R100: 10R; R_1206_3216Metric_Pad1.30x1.75mm_HandSolder
R86, R87, R88: 10KΩ; R_1206_3216Metric_Pad1.30x1.75mm_HandSolder
U1: MCP1754ST-3302E; SOT-223_3MC_MCH-M
U2: MCP1825S-3002E/DB; SOT-223_3MC_MCH-M
U3, U6, U7, U8, U9, U10, U11, U12, U14, U15, U16, U17: MCP6V97-E/MS; MSOP8_MS_MCH-M
U4: MIC39100-5.0WS; SOT-223_S_MCL-M
U5, U13, U18: MCP3564-E/ST; TSSOP20_ST_MCH-M

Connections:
+3.3VADC: C6.1, C18.1, C31.1, C44.1, J2.4, J3.4, J4.4, J5.4, J6.4, J7.4, J8.4, J9.4, J10.4, J11.4, J12.4, J13.4, J15.13, R22.1, R50.1, R78.1, U2.3 (VOUT), U3.8 (VDD), U5.4 (REFIN+), U6.8 (VDD), U7.8 (VDD), U8.8 (VDD), U9.8 (VDD), U10.8 (VDD), U11.8 (VDD), U12.8 (VDD), U13.4 (REFIN+), U14.8 (VDD), U15.8 (VDD), U16.8 (VDD), U17.8 (VDD), U18.4 (REFIN+)
+3.3VDAC: C7.1, C8.1, C9.1, L1.2, R23.1, R51.1, R79.1, R86.1, R87.1, R88.1
+5V: C2.1, C4.1, C5.1, R1.2, U1.1 (VIN), U2.1 (VIN), U4.3 (OUT)
ADC_IRQ_0: R97.1, U5.17 (*IRQ/MDAT)
ADC_IRQ_1: R99.1, U18.17 (*IRQ/MDAT)
ADC_IRQ_2: R25.1, U13.17 (*IRQ/MDAT)
CS_0: R86.2, R92.2, U5.13 (*CS)
CS_1: R87.2, R100.1, U18.13 (*CS)
CS_2: R26.2, R88.2, U13.13 (*CS)
GND: C2.2, C3.2, D2.1 (K), J1.2, J1.3, NT1.1, NT2.1, U4.2 (GND), U4.4
GNDA: C4.2, C5.2, C6.2, C10.2, C11.2, C12.2, C13.2, C14.2, C15.2, C16.2, C17.2, C18.2, C19.2, C20.2, C23.2, C24.2, C25.2, C26.2, C27.2, C28.2, C29.2, C30.2, C31.2, C32.2, C33.2, C36.2, C37.2, C38.2, C39.2, C40.2, C41.2, C42.2, C43.2, C44.2, C45.2, C46.2, J2.1, J3.1, J4.1, J5.1, J6.1, J7.1, J8.1, J9.1, J10.1, J11.1, J12.1, J13.1, J15.14, NT1.2, U2.2 (GND), U3.4 (VSS), U5.2 (AGND), U5.3 (REFIN-), U6.4 (VSS), U7.4 (VSS), U8.4 (VSS), U9.4 (VSS), U10.4 (VSS), U11.4 (VSS), U12.4 (VSS), U13.2 (AGND), U13.3 (REFIN-), U14.4 (VSS), U15.4 (VSS), U16.4 (VSS), U17.4 (VSS), U18.2 (AGND), U18.3 (REFIN-)
GNDD: C7.2, C8.2, C9.2, C21.2, C22.2, C34.2, C35.2, C47.2, C48.2, NT2.2, U1.2 (GND), U5.19 (DGND), U13.19 (DGND), U18.19 (DGND)
MCLK_0: R96.1, U5.18 (MCLKIN)
MCLK_1: R98.1, U18.18 (MCLKIN)
MCLK_2: R24.2, U13.18 (MCLKIN)
MISO: R95.1, U5.16 (SDO), U13.16 (SDO), U18.16 (SDO)
MOSI: R94.1, U5.15 (SDI), U13.15 (SDI), U18.15 (SDI)
unnamed: D1.2 (A), J1.1
unnamed: C3.1, D1.1 (K), U4.1 (EN)
unnamed: D2.2 (A), R1.1
unnamed: J2.2, U3.3 (VINA+)
unnamed: J2.3, U3.5 (VINB+)
unnamed: J3.2, U6.3 (VINA+)
unnamed: J3.3, U6.5 (VINB+)
unnamed: J4.2, U7.3 (VINA+)
unnamed: J4.3, U7.5 (VINB+)
unnamed: J5.2, U10.3 (VINA+)
unnamed: J5.3, U10.5 (VINB+)
unnamed: J6.2, U8.3 (VINA+)
unnamed: J6.3, U8.5 (VINB+)
unnamed: J7.2, U9.3 (VINA+)
unnamed: J7.3, U9.5 (VINB+)
unnamed: J8.2, U11.3 (VINA+)
unnamed: J8.3, U11.5 (VINB+)
unnamed: J9.2, U12.3 (VINA+)
unnamed: J9.3, U12.5 (VINB+)
unnamed: J10.2, U14.3 (VINA+)
unnamed: J10.3, U14.5 (VINB+)
unnamed: J11.2, U15.3 (VINA+)
unnamed: J11.3, U15.5 (VINB+)
unnamed: J12.2, U16.3 (VINA+)
unnamed: J12.3, U16.5 (VINB+)
unnamed: J13.2, U17.3 (VINA+)
unnamed: J13.3, U17.5 (VINB+)
unnamed: J15.1, R92.1
unnamed: J15.2, R93.2
unnamed: J15.3, R94.2
unnamed: J15.4, R95.2
unnamed: J15.5, R96.2
unnamed: J15.6, R97.2
unnamed: J15.7, R98.2
unnamed: J15.8, R99.2
unnamed: J15.9, R100.2
unnamed: J15.10, R24.1
unnamed: J15.11, R25.2
unnamed: J15.12, R26.1
unnamed: L1.1, U1.3 (VOUT)
unnamed: R2.1, R3.2, U3.2 (VINA-)
unnamed: R2.2, R4.1, U3.6 (VINB-)
unnamed: R3.1, R5.1, U3.1 (VOUTA)
unnamed: R4.2, R6.1, U3.7 (VOUTB)
unnamed: C19.1, C20.1, R22.2, U5.1 (AVDD)
unnamed: C11.1, R5.2, U5.5 (CH0)
unnamed: C10.1, R6.2, U5.6 (CH1)
unnamed: C13.1, R11.2, U5.7 (CH2)
unnamed: C12.1, R10.2, U5.8 (CH3)
unnamed: C15.1, R16.2, U5.9 (CH4)
unnamed: C14.1, R15.2, U5.10 (CH5)
unnamed: C16.1, R20.2, U5.11 (CH6)
unnamed: C17.1, R21.2, U5.12 (CH7)
unnamed: C21.1, C22.1, R23.2, U5.20 (DVDD)
unnamed: R7.2, R8.1, U6.2 (VINA-)
unnamed: R8.2, R9.1, U6.6 (VINB-)
unnamed: R7.1, R11.1, U6.1 (VOUTA)
unnamed: R9.2, R10.1, U6.7 (VOUTB)
unnamed: R12.2, R13.1, U7.2 (VINA-)
unnamed: R13.2, R14.1, U7.6 (VINB-)
unnamed: R12.1, R16.1, U7.1 (VOUTA)
unnamed: R14.2, R15.1, U7.7 (VOUTB)
unnamed: R30.2, R34.1, U8.2 (VINA-)
unnamed: R34.2, R38.1, U8.6 (VINB-)
unnamed: R30.1, R46.1, U8.1 (VOUTA)
unnamed: R38.2, R42.1, U8.7 (VOUTB)
unnamed: R31.2, R35.1, U9.2 (VINA-)
unnamed: R35.2, R39.1, U9.6 (VINB-)
unnamed: R31.1, R47.1, U9.1 (VOUTA)
unnamed: R39.2, R43.1, U9.7 (VOUTB)
unnamed: R17.2, R18.1, U10.2 (VINA-)
unnamed: R18.2, R19.1, U10.6 (VINB-)
unnamed: R17.1, R21.1, U10.1 (VOUTA)
unnamed: R19.2, R20.1, U10.7 (VOUTB)
unnamed: R32.2, R36.1, U11.2 (VINA-)
unnamed: R36.2, R40.1, U11.6 (VINB-)
unnamed: R32.1, R48.1, U11.1 (VOUTA)
unnamed: R40.2, R44.1, U11.7 (VOUTB)
unnamed: R33.2, R37.1, U12.2 (VINA-)
unnamed: R37.2, R41.1, U12.6 (VINB-)
unnamed: R33.1, R49.1, U12.1 (VOUTA)
unnamed: R41.2, R45.1, U12.7 (VOUTB)
unnamed: C32.1, C33.1, R50.2, U13.1 (AVDD)
unnamed: C28.1, R47.2, U13.5 (CH0)
unnamed: C24.1, R43.2, U13.6 (CH1)
unnamed: C29.1, R48.2, U13.7 (CH2)
unnamed: C25.1, R44.2, U13.8 (CH3)
unnamed: C30.1, R49.2, U13.9 (CH4)
unnamed: C26.1, R45.2, U13.10 (CH5)
unnamed: C27.1, R46.2, U13.11 (CH6)
unnamed: C23.1, R42.2, U13.12 (CH7)
unnamed: C34.1, C35.1, R51.2, U13.20 (DVDD)
unnamed: R58.2, R62.1, U14.2 (VINA-)
unnamed: R62.2, R66.1, U14.6 (VINB-)
unnamed: R58.1, R74.1, U14.1 (VOUTA)
unnamed: R66.2, R70.1, U14.7 (VOUTB)
unnamed: R59.2, R63.1, U15.2 (VINA-)
unnamed: R63.2, R67.1, U15.6 (VINB-)
unnamed: R59.1, R75.1, U15.1 (VOUTA)
unnamed: R67.2, R71.1, U15.7 (VOUTB)
unnamed: R60.2, R64.1, U16.2 (VINA-)
unnamed: R64.2, R68.1, U16.6 (VINB-)
unnamed: R60.1, R76.1, U16.1 (VOUTA)
unnamed: R68.2, R72.1, U16.7 (VOUTB)
unnamed: R61.2, R65.1, U17.2 (VINA-)
unnamed: R65.2, R69.1, U17.6 (VINB-)
unnamed: R61.1, R77.1, U17.1 (VOUTA)
unnamed: R69.2, R73.1, U17.7 (VOUTB)
unnamed: C45.1, C46.1, R78.2, U18.1 (AVDD)
unnamed: C37.1, R71.2, U18.5 (CH0)
unnamed: C41.1, R75.2, U18.6 (CH1)
unnamed: C42.1, R76.2, U18.7 (CH2)
unnamed: C38.1, R72.2, U18.8 (CH3)
unnamed: C43.1, R77.2, U18.9 (CH4)
unnamed: C39.1, R73.2, U18.10 (CH5)
unnamed: C40.1, R74.2, U18.11 (CH6)
unnamed: C36.1, R70.2, U18.12 (CH7)
unnamed: C47.1, C48.1, R79.2, U18.20 (DVDD)
SCK: R93.1, U5.14 (SCK), U13.14 (SCK), U18.14 (SCK)

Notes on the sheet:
Load cell plus
Load cell minus
Gain (100x)

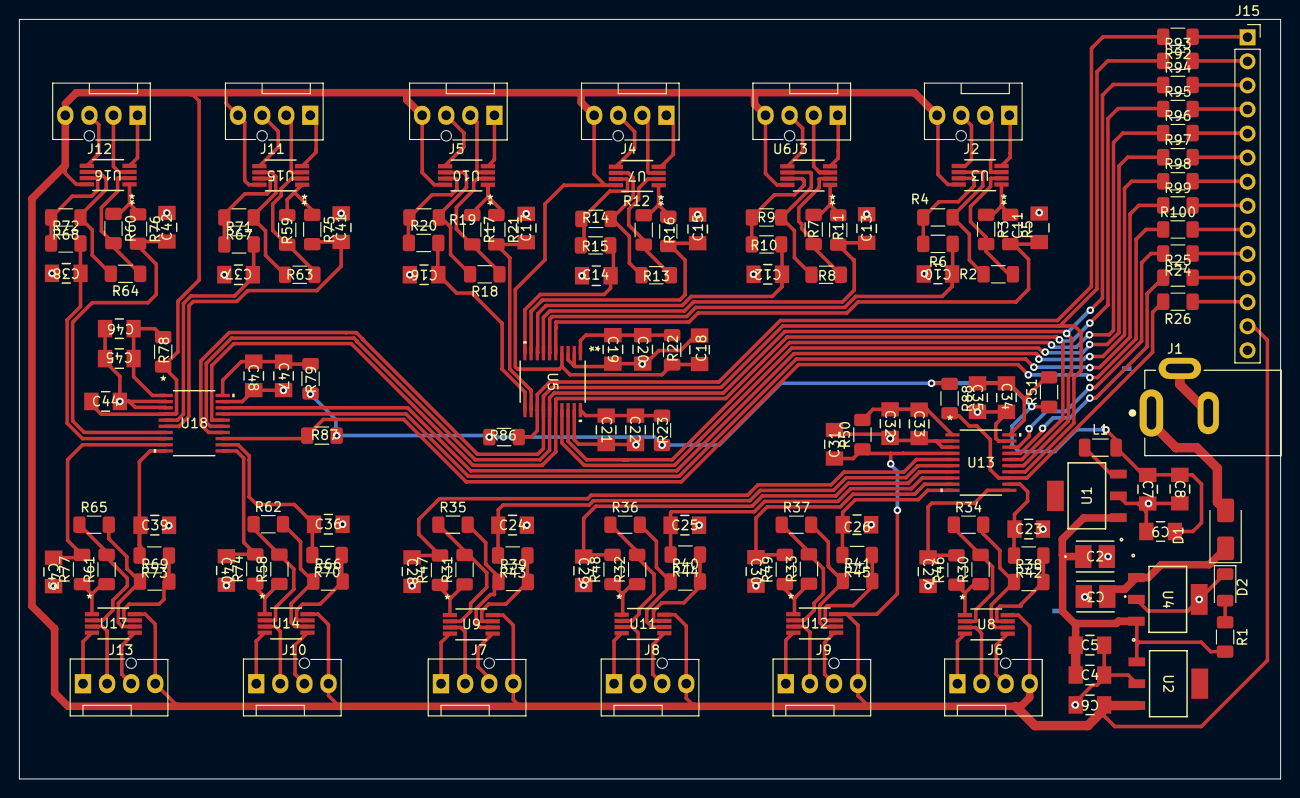
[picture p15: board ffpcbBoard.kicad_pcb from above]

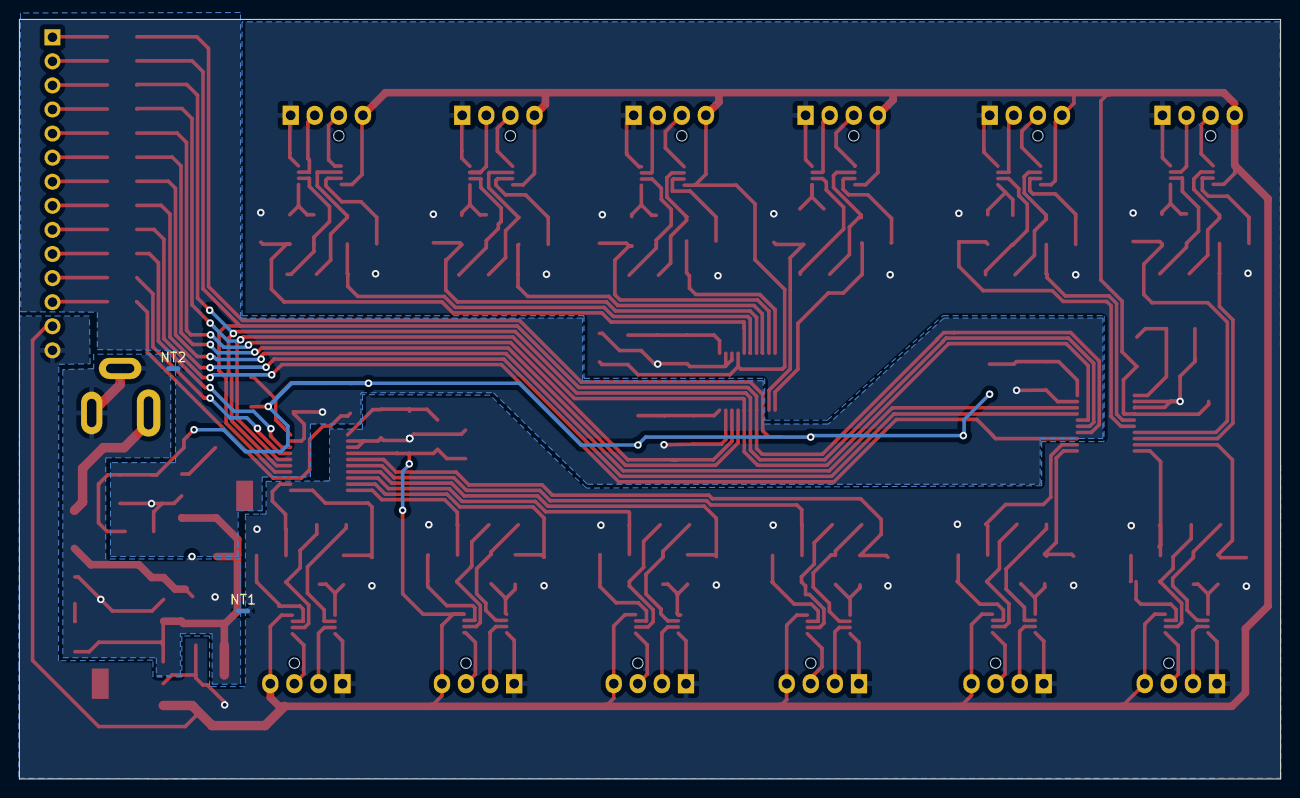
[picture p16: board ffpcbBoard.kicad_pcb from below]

Board: 2 copper layers, 133.0 x 80.1 mm, 166 parts (2 on the bottom side), 136 nets.

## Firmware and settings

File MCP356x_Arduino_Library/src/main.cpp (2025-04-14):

/**
 * @file mcp356x_basic_differential_reading.cpp
 * @brief Basic example demonstrating differential channel reading with the MCP356x ADC.
 *
 * This example demonstrates the fundamental operation of the MCP356x ADC for reading a
 * differential channel. It configures the ADC, initializes SPI communication, and
 * periodically reads both raw ADC values and voltage measurements from the DIFF_A channel.
 * The readings are printed to the serial console every 5 seconds, along with timing information.
 *
 * @author Jose Luis Berna Moya
 * @date Last Updated: March 2025
 * @version 1.0
 *
 * Hardware Connections:
 * - SDI_PIN (11): Connect to MCP356x SDI (Serial Data Input)
 * - SDO_PIN (12): Connect to MCP356x SDO (Serial Data Output)
 * - SCK_PIN (13): Connect to MCP356x SCK (Serial Clock Input)
 * - ADC_IRQ_PIN (6): Connect to MCP356x IRQ (Interrupt Request)
 * - ADC_CS_PIN (7): Connect to MCP356x CS (Chip Select)
 */

 #include "Arduino.h"
 #include "MCP356x.h"
 
 // Pin definitions for SPI communication
 #define SDI_PIN 11
 #define SDO_PIN 12
 #define SCK_PIN 13
 #define ADC_IRQ_PIN 6
 #define ADC_CS_PIN 7
 
 // Global variables
 unsigned long startTime;
 
 /**
  * @brief MCP356x ADC configuration structure
  *
  * This structure defines the hardware connections and operational parameters
  * for the MCP356x ADC.
  */
 MCP356xConfig config = {
     .irq_pin = ADC_IRQ_PIN,                     // Interrupt Request pin
     .cs_pin = ADC_CS_PIN,                       // Chip Select pin
     .mclk_pin = 0,                              // Master Clock pin (0 for internal clock)
     .addr = 0x01,                               // Device address (GND in this case)
     .spiInterface = &SPI,                       // SPI interface to use
     .numChannels = 1,                           // Number of channels to scan
     .osr = MCP356xOversamplingRatio::OSR_32,    // Oversampling ratio
     .gain = MCP356xGain::GAIN_1,                // Gain setting (1x)
     .mode = MCP356xADCMode::ADC_CONVERSION_MODE // Continuous conversion mode
 };
 
 // Pointer for dynamically created ADC object
 MCP356x *adc = nullptr;
 
 /**
  * @brief Setup function run once at startup
  *
  * Initializes serial communication, SPI interface, and the MCP356x ADC.
  */
 void setup()
 {
     // Initialize serial communication
     Serial.begin(115200);
     while (!Serial)
     {
         delay(10); // Wait for serial port to connect
     }
 
     // Initialize SPI interface
     SPI.setSCK(SCK_PIN);
     SPI.setMISO(SDO_PIN);
     SPI.setMOSI(SDI_PIN);
     SPI.begin();
 
     // Alternative pin configurations (commented out)
     // config.irq_pin = 3; config.cs_pin = 2; // For a second ADC
     // config.irq_pin = 5; config.cs_pin = 4; // For a third ADC
 
     // Create and initialize the ADC
     adc = new MCP356x(config);
 
     // Set initial time reference
     startTime = millis();
 }
 
 /**
  * @brief Main program loop
  *
  * Continuously checks for updated ADC readings. Every 5 seconds,
  * reads voltage and raw ADC values and prints them to the serial console.
  */
 void loop()
 {
     // Check for updated ADC readings (polling approach)
     // Uncomment the below block to implement polling
     /*
     if (adc->updatedReadings()) {
         // Process new readings here if needed
     }
     */
 
     // Every 5 seconds, read and print ADC values
     if (millis() - startTime >= 5000)
     {
         // Get voltage value from the differential channel A
         float voltage = adc->valueAsVoltage(MCP356xChannel::DIFF_A);
 
         // Get raw ADC value
         int32_t adcValue = adc->value(MCP356xChannel::DIFF_A);
 
         // Format and print the ADC value, voltage, and timing information
         StringBuilder output;
         output.concatf("ADC Value: %ld, Voltage: %.2fV\n", adcValue, voltage);
 
         // Print detailed timing information
         adc->printTimings(&output);
 
         // Output the formatted string
         if (output.length() > 0)
         {
             Serial.print((char *)output.string());
         }
 
         // Reset timer for the next interval
         startTime = millis();
     }
 }

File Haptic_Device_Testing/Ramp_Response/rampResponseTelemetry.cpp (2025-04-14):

#include <MCP356x6axis.h>

// Pin Definitions
#define SDI_PIN 11
#define SDO_PIN 12
#define SCK_PIN 13
#define CS_PIN0 7
#define IRQ_PIN0 6
#define CS_PIN1 4
#define IRQ_PIN1 5
#define CS_PIN2 2
#define IRQ_PIN2 3
#define MOTOR_PWM_PIN 9          // PWM pin connected to the motor controller
#define RAMP_UP_DURATION 10000   // 10 seconds ramp up duration
#define RAMP_DOWN_DURATION 10000 // 10 seconds ramp down duration
#define HOLD_DURATION 5000       // 5 seconds hold duration at max and min
#define TOTAL_CYCLE_DURATION (RAMP_UP_DURATION + HOLD_DURATION + RAMP_DOWN_DURATION + HOLD_DURATION)

#define TOTAL_NUM_CELLS 12
#define SAMPLE_INTERVAL 10 // Sample interval set to 20ms

MCP356xScale *mcpScale = nullptr;
MCP356x3axis *loadCell1 = nullptr;
MCP356x3axis *loadCell2 = nullptr;
MCP356x3axis *loadCell3 = nullptr;
MCP356x3axis *loadCell4 = nullptr;
MCP356x6axis *sixAxisLoadCell = nullptr;

unsigned long cycleStartTime;
bool cycleComplete = false;
int lastSentPWMValue = -1;

// Variables for averaging
unsigned int sampleCount = 0;
Matrix<3, 1> totalReadings1 = {0, 0, 0};
Matrix<3, 1> totalReadings2 = {0, 0, 0};
Matrix<3, 1> totalReadings3 = {0, 0, 0};
Matrix<3, 1> totalReadings4 = {0, 0, 0};

void initializeCalibrationWithMatrices()
{
    BLA::Matrix<3, 3> calibMatrix1 = {
        -5.982118e-04, -6.398772e-06, 1.493637e-05,
        -1.610696e-05, 5.980800e-04, 1.154983e-05,
        5.832123e-06, -5.437381e-06, 6.200539e-04};

    // For Load Cell 2
    BLA::Matrix<3, 3> calibMatrix2 = {
        5.981983e-04, -1.070736e-05, 7.760431e-06,
        2.589967e-06, 5.869149e-04, 6.217067e-06,
        5.954714e-06, 1.355531e-05, 5.982035e-04};

    // For Load Cell 3
    BLA::Matrix<3, 3> calibMatrix3 = {
        -5.967505e-04, -1.410111e-05, -1.031143e-05,
        -1.276690e-05, 5.953475e-04, -4.933627e-06,
        8.278846e-06, -1.064470e-05, -5.746296e-04};

    // For Load Cell 4
    BLA::Matrix<3, 3> calibMatrix4 = {
        -6.007485e-04, -1.092638e-05, -2.390023e-06,
        -1.328377e-05, 5.968730e-04, 5.299463e-06,
        3.958772e-06, -7.053156e-06, 6.141198e-04};

    loadCell1->setCalibrationMatrix(calibMatrix1);
    loadCell2->setCalibrationMatrix(calibMatrix2);
    loadCell3->setCalibrationMatrix(calibMatrix3);
    loadCell4->setCalibrationMatrix(calibMatrix4);
}

void initializeCalibrationWithpolynomial()
{
    // Set Polynomial Calibration for Load Cell 1
    loadCell1->setCalibrationPolynomial(
        {-2.828916e+02, -6.139373e-04, -4.779867e-12}, // X Axis
        {3.592542e+02, 5.951776e-04, 1.063187e-11},    // Y Axis
        {-5.722137e+02, 6.244786e-04, -9.493906e-12}   // Z Axis
    );

    // Set Polynomial Calibration for Load Cell 2
    loadCell2->setCalibrationPolynomial(
        {-1.517346e+02, 6.002052e-04, -7.213967e-13}, // X Axis
        {3.217731e+02, 5.941050e-04, -7.526178e-12},  // Y Axis
        {-6.883740e+02, 5.964100e-04, 4.769434e-12}   // Z Axis
    );

    loadCell3->setCalibrationPolynomial(
        {4.924497e+02, -6.000414e-04, -5.842038e-12}, // X Axis
        {4.065573e+02, 5.873697e-04, -3.809444e-12},  // Y Axis
        {-3.722284e+02, -5.611561e-04, 4.556780e-12}  // Z Axis
    );

    loadCell4->setCalibrationPolynomial(
        {-1.973620e+01, -6.040589e-04, -8.463602e-13}, // X Axis
        {5.351286e+02, 5.982422e-04, 4.519417e-12},    // Y Axis
        {-2.636953e+02, 5.996329e-04, 5.869018e-12}    // Z Axis
    );
    loadCell1->tare(100);
    loadCell2->tare(100);
    loadCell3->tare(100);
    loadCell4->tare(100);
}

int rampController()
{
    unsigned long currentTime = millis();
    unsigned long elapsedTime = currentTime - cycleStartTime;
    unsigned long phaseTime = elapsedTime % TOTAL_CYCLE_DURATION;
    int pwmValue = 0;

    // Determine the current PWM value based on the ramp-up/down and hold phases
    if (phaseTime <= RAMP_UP_DURATION)
    {
        pwmValue = map(phaseTime, 0, RAMP_UP_DURATION, 0, 255);
    }
    else if (phaseTime <= RAMP_UP_DURATION + HOLD_DURATION)
    {
        pwmValue = 255;
    }
    else if (phaseTime <= RAMP_UP_DURATION + HOLD_DURATION + RAMP_DOWN_DURATION)
    {
        pwmValue = map(phaseTime, RAMP_UP_DURATION + HOLD_DURATION, RAMP_UP_DURATION + HOLD_DURATION + RAMP_DOWN_DURATION, 255, 0);
    }
    else
    {
        pwmValue = 0;
    }

    // when the PWM changes update the actuator
    if (pwmValue != lastSentPWMValue)
    {
        analogWrite(MOTOR_PWM_PIN, pwmValue); // controlling the actuator via PWM
        Serial1.println(pwmValue);            // controlling the actuator via Serial message
        // If using an ESC, replace analogWrite with ESC-specific command
        // esc.setSpeed(map(newPWMValue, 0, 255, ESC_MIN_VALUE, ESC_MAX_VALUE));
        lastSentPWMValue = pwmValue; // Update the last sent value
    }

    // Restart the cycle automatically for continuous operation
    if (elapsedTime > TOTAL_CYCLE_DURATION)
    {
        cycleStartTime = currentTime; // Reset cycle start time
    }

    return pwmValue; // Optional, depending on if you need the value in loop()
}
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

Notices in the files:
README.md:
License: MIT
